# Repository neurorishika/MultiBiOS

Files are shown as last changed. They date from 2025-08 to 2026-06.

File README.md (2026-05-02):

# MultiBiOS: Precision Olfactometer Control System

<div align="center">









**High-precision, hardware-clocked olfactometer control system for behavioral neuroscience**

[📚 Documentation](https://neurorishika.github.io/MultiBiOS/) • [🚀 Quick Start](#quick-start) • [🔧 Installation](#installation) • [📖 Examples](#examples) • [🤝 Contributing](#contributing)

</div>

---

## 🧪 Overview

**MultiBiOS** (Multispecies Bilateral Odor delivery System) is a precision olfactometer control system designed for behavioral neuroscience experiments. It provides sub-millisecond timing control, complete experimental reproducibility, and comprehensive data logging.

### ✨ Key Features

- 🎯 **Sub-millisecond precision** with hardware-clocked timing via NI-DAQ
- 🔄 **Bilateral valve control** for complex comparative experiments  
- 📊 **Complete data provenance** with comprehensive logging and replay
- 🛡️ **Built-in safety guardrails** prevent timing conflicts at compile-time
- 🎲 **Reproducible randomization** via configurable random seeds
- 📈 **Interactive visualization** with real-time and post-hoc analysis
- ⏱️ **Real-time progress monitoring** shows expected protocol state during execution
- 🔌 **Teensy 4.1 firmware** for microsecond-precise valve preloading
- 📝 **YAML protocols** for human-readable experimental descriptions

### 🏗️ System Architecture

```
┌─────────────────┐    ┌─────────────────┐    ┌─────────────────┐
│   YAML Protocol │───▶│ Python Compiler │───▶│   NI-DAQ USB    │
│   Description   │    │   & Runner      │    │    6353         │
└─────────────────┘    └─────────────────┘    └─────────────────┘
                                                        │
                                                        ▼
                              ┌─────────────────────────────────────┐
                              │          Teensy 4.1 MCU             │
                              │    (Valve Pattern Preloading)      │
                              └─────────────────────────────────────┘
                                                │
                                                ▼
                              ┌─────────────────────────────────────┐
                              │       TPIC6B595 Shift Registers    │
                              │         (10MHz SPI Chain)          │
                              └─────────────────────────────────────┘
                                                │
                                                ▼
                              ┌─────────────────────────────────────┐
                              │      Olfactometer Valve Arrays     │
                              │    (8-valve bilateral control)     │
                              └─────────────────────────────────────┘
```

## 🚀 Quick Start

### Prerequisites

- Conda or Miniconda
- NI-DAQmx drivers (for hardware execution)
- Spinnaker SDK 4.3.0.189 installed on Windows before installing `PySpin`
- If you want live Blackfly input in FicTrac on this rig, build a Spinnaker-enabled FicTrac binary and configure the `fictrac` block in `config/hardware.yaml`

### Installation

```bash
# Clone the repository
git clone https://github.com/neurorishika/MultiBiOS.git
cd MultiBiOS

# Create the shared NI-DAQ + Blackfly camera environment
conda env create -f environment.yml
conda activate multibios-blackfly

# Verify the combined stack
python -c "import multibios, nidaqmx, PySpin; print('multibios-blackfly ready')"

# Optional app smoke tests
multibios-explorer --help
multibios-flow-monitor --help
```

This environment is intended to run both the MultiBiOS DAQ stack and the Blackfly camera scripts in one place. The rig camera model is **Teledyne FLIR Blackfly S BFS-U3-13Y3M**.

For live FicTrac on the Blackfly side camera, see `docs/fictrac.md`. MultiBiOS now prepares the Spinnaker runtime DLL path automatically before launching FicTrac, but you still need a FicTrac binary built with the upstream `PGR_USB3` option.

If you are on this workstation and want the same validated build that was used for the Blackfly side camera, run:

```powershell
cd C:\Rishika\MultiBiOS
.\tools\build_fictrac_spinnaker.ps1 -VcpkgRoot C:\Users\markd\vcpkg
```

The resulting binary is expected at `assets/fictrac-spinnaker/fictrac-spinnaker.exe`. The step-by-step build and usage guide lives in `docs/fictrac.md`.

FicTrac is treated as vendored source in this repo because MultiBiOS carries source-level patches in `assets/third_party/FicTrac`. The local build directory `assets/third_party/FicTrac-build` should remain untracked.

### Your First Protocol

1. **Preview a protocol** (no hardware required):
   ```bash
     python -m multibios.run_protocol \
      --yaml protocols/example_protocol.yaml \
       --hardware config/hardware.yaml \
       --dry-run --interactive
   ```

2. **Run on hardware** (requires NI-DAQ setup):
   ```bash
     python -m multibios.run_protocol \
      --yaml protocols/example_protocol.yaml \
       --hardware config/hardware.yaml
   ```

3. **Run with real-time progress monitoring**:
   ```bash
     python -m multibios.run_protocol \
      --yaml protocols/example_protocol.yaml \
       --hardware config/hardware.yaml \
       --verbose --progress
   ```
   
   This displays the expected protocol state during execution:
   ```
   DO Legend: [0:RCK] [1:LOAD_REQ] [2:S0] [3:S1] [4:S2]
   AO Legend: [0:MFC1] [1:MFC2]
   [  5%] 250.0ms | DO:░█░░█ | AO:0:2.50,1:1.20
   [ 10%] 500.0ms | DO:█░█░░ | AO:0:3.00,1:1.50
   ```
   (█=HIGH, ░=LOW, shows all channels at once!)

4. **Analyze results**:
   ```bash
  python -m multibios.viz_protocol data/runs/latest
   ```

## 📖 Examples

### Simple Bilateral Odor Delivery

```yaml
protocol:
  name: "Bilateral Odor Comparison"
  timing:
    sample_rate: 1000  # 1 kHz sampling
    seed: 42          # Reproducible randomization

sequence:
  - phase: "Baseline"
    duration: 30000   # 30 seconds
    times: 1
    actions:
      - device: "olfactometer.left"
        state: "AIR"
        timing: 0
      - device: "olfactometer.right"
        state: "AIR"
        timing: 0

  - phase: "Odor Presentation" 
    duration: 60000   # 1 minute per trial
    times: 5          # 5 trials
    randomize: true   # Randomize odor order
    actions:
      - device: "olfactometer.left"
        state: "ODOR1,ODOR2,ODOR3"  # Random selection
        timing: 10000               # 10s into trial
      - device: "triggers.microscope"
        state: true
        timing: 15000               # Trigger at 15s
```

### Advanced Multi-Device Coordination

```yaml
sequence:
  - phase: "Complex Trial"
    duration: 45000
    times: 10
    actions:
      # MFC setpoints
      - device: "mfc.air_left_setpoint"
        value: 2.1  # Volts
        timing: 0
      
      # Synchronized valve switching  
      - device: "olfactometer.left"
        state: "ODOR1"
        timing: 5000
      - device: "switch_valve.left"
        state: "ODOR" 
        timing: 5100  # 100ms later
        
      # Continuous camera triggers
      - device: "triggers.camera_continuous"
        state: true
        timing: 1000
      - device: "triggers.camera_continuous" 
        state: false
        timing: 40000
```

## 🔧 Hardware Setup

### Required Components

| Component | Description | Quantity |
|---|---|---|
| **NI USB-6353** | Hardware-clocked DAQ | 1 |
| **Teensy 4.1** | Microcontroller for valve control | 1 |
| **TPIC6B595** | High-power shift registers | 4 |
| **Olfactometer valves** | Pneumatic valves (12V) | 8-16 |
| **Mass flow controllers** | Precision flow control | 2-4 |

### Wiring Overview

```
NI-DAQ ────┐
           ├─── LOAD_REQ (Hardware clock)
           ├─── S-bits (Device selection) 
           ├─── Analog I/O (MFC control)
           └─── Triggers (Microscope/Camera)

Teensy ────┐
           ├─── SPI Chain (10MHz)
           ├─── Interrupt handling
           └─── Safety interlocks

TPIC6B595 ─┼─── Valve Array Left
           ├─── Valve Array Right  
           ├─── Switch Valve Left
           └─── Switch Valve Right
```

📋 **[Complete wiring diagrams and setup instructions →](https://neurorishika.github.io/MultiBiOS/hardware/)**

## 📊 Data Output

MultiBiOS provides comprehensive data logging:

### Generated Files
```
data/runs/2025-08-21_14-07-33/
├── protocol_original.yaml      # Original protocol
├── protocol_compiled.yaml      # Compiled with timing  
├── hardware_config.yaml        # Hardware configuration
├── digital_output.npy          # DO timing arrays
├── analog_output.npy           # AO setpoints
├── analog_input.csv            # MFC feedback (if recorded)
├── timing_log.csv              # Execution timestamps
└── visualization.html          # Interactive plot
```

### Interactive Visualization

The system generates rich interactive plots showing:
- 📈 Commanded vs actual valve states
- 🎛️ Analog input/output traces  
- ⏱️ Timing precision analysis
- 🔍 Zoom and pan capabilities

## 🧪 Use Cases

MultiBiOS is designed for:

- **Behavioral choice experiments** with precise odor timing
- **Optogenetics** with synchronized light/odor delivery
- **Calcium imaging** with triggered acquisition
- **Electrophysiology** with sub-millisecond precision
- **Multi-animal** comparative studies
- **Reproducible protocols** across labs and sessions

## 🛡️ Safety & Reliability

### Built-in Safeguards
- ✅ **Compile-time validation** prevents hardware conflicts
- ✅ **Timing guardrails** ensure safe valve switching
- ✅ **State verification** with sticky S-bit monitoring  
- ✅ **Hardware interlocks** prevent damage
- ✅ **Complete logging** for audit trails

### Experimental Reproducibility
- 🎯 **Deterministic randomization** with configurable seeds
- 📝 **Complete parameter logging** 
- 🔄 **Protocol replay** capability
- 📊 **Timing validation** and verification
- 🏷️ **Version tracking** of all components

## 📚 Documentation

Comprehensive documentation is available at **[neurorishika.github.io/MultiBiOS](https://neurorishika.github.io/MultiBiOS/)**

### Quick Links
- 🏗️ [System Architecture](https://neurorishika.github.io/MultiBiOS/hardware/)
- 🔌 [Hardware Setup](https://neurorishika.github.io/MultiBiOS/wiring/) 
- 💾 [Firmware Guide](https://neurorishika.github.io/MultiBiOS/firmware/)
- 📝 [Protocol Reference](https://neurorishika.github.io/MultiBiOS/protocol/)
- 🏃 [Runner Application](https://neurorishika.github.io/MultiBiOS/runner/)
- 📈 [Visualization](https://neurorishika.github.io/MultiBiOS/visualization/)
- ❓ [FAQ](https://neurorishika.github.io/MultiBiOS/faq/)
- 🔧 [Troubleshooting](https://neurorishika.github.io/MultiBiOS/troubleshooting/)

## 🤝 Contributing

We welcome contributions! MultiBiOS is built for the neuroscience community.

### Ways to Contribute
- 🐛 **Report bugs** and request features
- 💡 **Submit improvements** to code or documentation  
- 🧪 **Share protocols** and use cases
- 🔧 **Hardware modifications** and extensions
- 📚 **Documentation** improvements

### Getting Started
```bash
# Fork the repository on GitHub
git clone https://github.com/yourusername/MultiBiOS.git
cd MultiBiOS

# Install development dependencies
poetry install --with dev

# Run tests
poetry run pytest

# Format code
poetry run black multibios/
poetry run ruff check multibios/
```

### Test And Tool Layout

- `tests/` is reserved for automated `pytest` coverage.
- `tools/manual_checks/` is for operator-facing hardware checks, probes, and bench scripts that are meant to be run directly.
- When adding new validation code, put reusable automated assertions under `tests/` and keep live camera, DAQ, MFC, or FicTrac helpers under `tools/manual_checks/`.

For a quick automated smoke pass from the repo root, run:

```bash
pytest tests/
```

📖 **[Full contributing guide →](https://neurorishika.github.io/MultiBiOS/contributing/)**

## 📄 License

This project is licensed under the MIT License - see the [LICENSE](LICENSE) file for details.

## 🙏 Acknowledgments

MultiBiOS was developed for the neuroscience research community. Special thanks to:
- The **Ruta and Kronauer Labs** for requirements and testing
- **National Instruments** for DAQ hardware support  
- The **Arduino/Teensy** community for firmware foundations
- **Open source contributors** who make science better

## 📞 Contact

- **Issues & Support:** [GitHub Issues](https://github.com/neurorishika/MultiBiOS/issues)
- **Email:** neurorishika@gmail.com  
- **Documentation:** [neurorishika.github.io/MultiBiOS](https://neurorishika.github.io/MultiBiOS/)

---

<div align="center">

**🧠 Built for Neuroscience • 🔬 Made with Science • 🚀 Open Source**

[⭐ Star this repo](https://github.com/neurorishika/MultiBiOS/stargazers) • [📖 Read the docs](https://neurorishika.github.io/MultiBiOS/) • [🤝 Contribute](CONTRIBUTING.md)

</div>

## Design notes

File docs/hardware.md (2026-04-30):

# System Architecture

The system separates **state preparation** from **state commit**:

1. **Teensy 4.1** drives SPI MOSI/SCK to all TPIC6B595 chains (no latches).
2. **NI-DAQ** provides:
   - Digital lines for **state selection** (`*_S0/_S1/_S2` or `*_S`) and **LOAD_REQ**.
   - **Register clocks** (`RCK_*`) to latch TPIC outputs—this is the *commit* moment.
   - Triggers to external devices (e.g., microscope, camera).
   - Analog outputs (AO) to set **MFC setpoints**.
   - Analog inputs (AI) to read **MFC flow feedback** (0–5 V).

**Key idea**: the Teensy preloads the next pattern when `*_LOAD_REQ` rises (it samples S-bits), then waits. The DAQ later asserts `RCK_*` to commit the preload. The DAQ can timestamp RCK edges precisely (hardware clock).

## Hardware Blocks

- **Valve drivers**: TPIC6B595 (open-drain high-side sinking arrays).
- **Big olfactometers**: two 16-bit manifolds (use 12 bits now; 4 spares).
- **Small switch valves**: two 2-valve assemblies (8-bit register each; only 2 bits used).
- **MFCs**: Four channels (air L/R, odor L/R). AO setpoint (0–5 V), AI feedback (0–5 V).
- **Timing**: NI USB-6353 sample clock slaves AO & AI to DO.

## Camera Rig

- **Front camera**: Teledyne FLIR Blackfly S BFS-U3-13Y3M, Mono8, USB3
- **Side/FicTrac camera**: Teledyne FLIR Blackfly S BFS-U3-13Y3M, Mono8, USB3
- **Camera SDK**: Spinnaker / PySpin 4.3.0.189 on Windows
- **Shared environment**: `multibios-blackfly`

GPIO findings verified on the live rig cameras:

- `Line1` is the white-wire return path and reports as `OptoCoupled`
- `Line2` is a separate GPIO path and reports as `OpenDrain`
- the blue wire is `Opto GND` for the isolated white-wire output

Documenting the exact camera model and software stack here is intentional: this rig assumes both camera positions use the same Blackfly S hardware so acquisition timing and synchronization checks are repeatable across rebuilds.

## Signal Naming (logical)

Digital outputs (from DAQ to Teensy/TPIC):

- **Left big olfactometer**: `OLFACTOMETER_LEFT_S0/_S1/_S2`, `OLFACTOMETER_LEFT_LOAD_REQ`, `RCK_OLFACTOMETER_LEFT`
- **Right big olfactometer**: `OLFACTOMETER_RIGHT_*` (same fields)
- **Left small switch**: `SWITCHVALVE_LEFT_S`, `SWITCHVALVE_LEFT_LOAD_REQ`, `RCK_SWITCHVALVE_LEFT`
- **Right small switch**: `SWITCHVALVE_RIGHT_*`
- **Triggers**: `TRIG_MICRO`, `TRIG_CAMERA`

Analog:

- **AO (setpoints)**: `mfc.air_left_setpoint`, `mfc.air_right_setpoint`, `mfc.odor_left_setpoint`, `mfc.odor_right_setpoint`
- **AI (feedback)**: `mfc.air_left_flowrate`, `mfc.air_right_flowrate`, `mfc.odor_left_flowrate`, `mfc.odor_right_flowrate`

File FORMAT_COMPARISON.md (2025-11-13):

# Progress Monitor Format Evolution

## Version 1: Original Verbose Format (REJECTED)

```
=== Real-time Progress Monitor Started ===
Protocol duration: 5.00s (5000 samples @ 1000Hz)
Update interval: 100ms

[  2.0%] [t=100.0ms] DO: RCK=LOW, LOAD_REQ=LOW, S0=LOW | AO: MFC1=0.000V, MFC2=0.000V
[  4.0%] [t=200.0ms] DO: RCK=LOW, LOAD_REQ=HIGH, S0=LOW | AO: MFC1=2.500V, MFC2=1.200V
```

**Problems:**
- ❌ Too wordy - hard to scan
- ❌ HIGH/LOW takes too much space
- ❌ Can only show 3-5 channels per line
- ❌ Hard to see patterns

## Version 2: Compact with Names (REJECTED)

```
Progress monitor: 5000 samples @ 1000Hz, updates every 100ms
[  2%] 100.0ms | RCK:░ LOAD_REQ:░ S0:░ S1:░ S2:░ | MFC1:0.00 MFC2:0.00
[  4%] 200.0ms | RCK:░ LOAD_REQ:█ S0:░ S1:█ S2:░ | MFC1:2.50 MFC2:1.20
```

**Better, but:**
- ⚠️ Long channel names still limit visibility
- ⚠️ Can only see 4-5 DO channels
- ⚠️ Shows all AO channels even when zero

## Version 3: Index-Based with Legend (CURRENT ✓)

```
Progress monitor: 5000 samples @ 1000Hz, updates every 100ms
DO Legend: [0:RCK] [1:LOAD_REQ] [2:S0] [3:S1] [4:S2] [5:S3] [6:S4] [7:S5]
AO Legend: [0:MFC1] [1:MFC2] [2:MFC3]
✓ All DAQ tasks started, protocol execution in progress...

[  2%] 100.0ms | DO:░░░░░░░░ | AO:---
[  4%] 200.0ms | DO:░█░█░░░░ | AO:0:2.50,1:1.20
[  6%] 300.0ms | DO:█░█░█░░░ | AO:0:2.50,1:1.20
[  8%] 400.0ms | DO:░░█░░░░░ | AO:0:2.50,1:1.20
[ 10%] 500.0ms | DO:░░░██░░░ | AO:0:1.80,1:0.80
```

**Perfect!**
- ✅ **Shows ALL DO channels** as visual pattern
- ✅ **Only shows active AO channels** (saves space)
- ✅ **Legend printed once** (no repetition)
- ✅ **Ultra-compact** - fits 16+ DO channels easily
- ✅ **Patterns instantly recognizable**

---

## Key Improvements

### 1. Digital Outputs: Pattern Display

**Old approach:**
```
RCK:░ LOAD_REQ:█ S0:░ S1:█ S2:░
```
- Limited to ~5 channels
- Repetitive names

**New approach:**
```
DO:░█░█░░░░
```
- Shows ALL channels
- Clear visual pattern
- Compact and scannable

### 2. Analog Outputs: Show Only Active

**Old approach:**
```
MFC1:0.00 MFC2:0.00 MFC3:0.00
```
- Wastes space on zeros
- Cluttered

**New approach:**
```
AO:---                    (when all zero)
AO:0:2.50,1:1.20         (only non-zero)
```
- Clean when inactive
- Focused on what matters

### 3. Legend System

**Printed once at startup:**
```
DO Legend: [0:RCK] [1:LOAD_REQ] [2:S0] [3:S1] [4:S2]
AO Legend: [0:MFC1] [1:MFC2] [2:MFC3]
```

Then every update just uses indices:
```
[  5%] 250.0ms | DO:░█░░█ | AO:0:2.50
```

**Benefits:**
- No name repetition
- Easy cross-reference
- Scales to many channels

---

## Real-World Examples

### Example 1: 16 Digital Outputs

**Old format would show:**
```
RCK:░ LOAD_REQ:█ S0:█ +13 more
```
😞 Can't see most channels!

**New format shows:**
```
DO:░█████░░░████████
```
😊 See everything at once!

### Example 2: Mostly Inactive MFCs

**Old format:**
```
MFC1:0.00 MFC2:0.00 MFC3:0.00 MFC4:0.00 MFC5:0.00
```
😞 Visual clutter

**New format:**
```
AO:---
```
😊 Clean and clear!

### Example 3: Few Active Channels

**Old format:**
```
MFC1:2.50 MFC2:0.00 MFC3:0.00 MFC4:1.20 MFC5:0.00
```
😞 Hard to spot which are active

**New format:**
```
AO:0:2.50,3:1.20
```
😊 Instantly see channels 0 and 3 are active!

---

## Capacity Comparison

| Format | Max DO Visible | Max AO Visible | Line Length |
|---|---|---|---|
| Version 1 | 3 | 2 | ~100 chars |
| Version 2 | 5 | 3 | ~80 chars |
| **Version 3** | **ALL** | **ALL active** | **~60 chars** |

---

## Pattern Recognition Benefits

The index-based format makes state sequences obvious:

```
[  2%] 100.0ms | DO:░░░░░░░░ | AO:---
[  4%] 200.0ms | DO:█░░░░░░░ | AO:0:2.50
[  6%] 300.0ms | DO:█░░░░░░░ | AO:0:2.50
[  8%] 400.0ms | DO:░█░░░░░░ | AO:0:2.50
[ 10%] 500.0ms | DO:░░█░░░░░ | AO:0:2.50
[ 12%] 600.0ms | DO:░░░█░░░░ | AO:0:2.50
```

You can instantly see:
- First channel scanning across (walking 1-hot pattern)
- MFC stays constant during scan
- Clear temporal pattern

---

## Summary

The index-based format with legend is the **optimal solution** for real-time protocol monitoring:

1. **Scalability**: Shows unlimited DO channels
2. **Efficiency**: Only shows active AO channels
3. **Clarity**: Visual patterns are instantly recognizable
4. **Compactness**: Shortest possible lines
5. **Usability**: Legend maps indices to names

Perfect for monitoring complex protocols with many channels!

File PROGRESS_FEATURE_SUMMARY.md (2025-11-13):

# Real-Time Progress Monitoring - Implementation Summary

## What Was Added

### 1. Core Feature: `ProtocolProgressMonitor` Class
**Location**: `multibios/run_protocol.py`

A background thread-based monitor that displays expected protocol state during DAQ execution.

**Key capabilities:**
- Calculates expected sample position from elapsed time
- Looks up expected DO/AO states from compiled arrays
- Formats and displays state at configurable intervals
- Automatically starts/stops with DAQ execution
- Zero impact on hardware timing

### 2. Command-Line Arguments
**New flags in `run_protocol.py`:**

```bash
--progress                    # Enable real-time progress monitoring
--progress-interval <ms>      # Update interval (default: 100ms)
```

**Usage:**
```bash
python multibios/run_protocol.py \
    --yaml config/example_protocol.yaml \
    --hardware config/hardware.yaml \
    --verbose \
    --progress \
    --progress-interval 100
```

### 3. Example Scripts
**Windows PowerShell**: `examples/run_with_progress.ps1`
**Linux/Mac Bash**: `examples/run_with_progress.sh`

Demonstrate the feature with sensible defaults.

### 4. Documentation
- **Comprehensive guide**: `examples/README_PROGRESS.md`
- **Runner docs update**: `docs/runner.md` (added section on progress monitoring)
- **Main README update**: Added to feature list and quick start

## How It Works

### Architecture

```
┌─────────────────────┐
│  Main Thread        │
│  - DAQ Execution    │
│  - Task Management  │
└──────────┬──────────┘
           │
           │ Starts/Stops
           ▼
┌─────────────────────┐
│  Monitor Thread     │
│  - Time tracking    │
│  - State lookup     │
│  - Display updates  │
└─────────────────────┘
```

### Thread Safety
- Monitor runs in daemon thread (won't block program exit)
- Uses threading.Event for clean shutdown
- No shared mutable state (reads from compiled arrays)
- No DAQ polling (time-based calculation only)

### Performance
- **CPU overhead**: < 0.1%
- **Memory overhead**: Negligible (references existing arrays)
- **Timing impact**: None (independent of DAQ hardware clock)

## Example Output

### During Execution
```
=== Real-time Progress Monitor Started ===
Protocol duration: 5.00s (5000 samples @ 1000Hz)
Update interval: 100ms

✓ All DAQ tasks started, protocol execution in progress...

[  2.0%] [t=100.0ms] DO: RCK=LOW, LOAD_REQ=LOW, S0=LOW | AO: MFC1=0.000V, MFC2=0.000V
[  4.0%] [t=200.0ms] DO: RCK=LOW, LOAD_REQ=HIGH, S0=LOW | AO: MFC1=2.500V, MFC2=1.200V
[  6.0%] [t=300.0ms] DO: RCK=HIGH, LOAD_REQ=LOW, S0=HIGH | AO: MFC1=2.500V, MFC2=1.200V
...
[100.0%] Protocol execution complete

=== Real-time Progress Monitor Stopped ===
✓ Protocol execution completed in 5.02 seconds
```

### Format Breakdown
```
[  5.0%]              ← Progress percentage
[t=250.0ms]           ← Protocol timestamp
DO: RCK=LOW, ...      ← Digital output states (first 3 channels)
AO: MFC1=2.500V, ...  ← Analog output voltages (first 2 channels)
```

## Use Cases

### 1. Long Protocols
- Protocols lasting minutes to hours
- Provides reassurance that execution is proceeding
- Shows estimated completion

### 2. Protocol Development
- Verify state transitions
- Check timing of critical events
- Identify unexpected states

### 3. Debugging
- Pinpoint when issues occur
- Compare expected vs. actual behavior
- Narrow down problematic timing windows

### 4. User Demonstrations
- Show what's happening in real-time
- Build confidence in system operation
- Educational tool for understanding protocols

## Configuration Options

### Update Interval Guidelines

| Interval | Best For | Output Volume |
|---|---|---|
| 50ms | Detailed debugging, timing verification | High |
| 100ms | **Default** - General use, good balance | Medium |
| 200ms | Longer protocols, cleaner output | Low |
| 500ms | Very long protocols (hours), minimal updates | Very Low |

### Verbosity Levels

```bash
# Minimal output (progress only)
--progress

# Standard output (recommended)
--verbose --progress

# Maximum detail (debugging)
--debug --progress
```

## Integration Points

### Modified Code Sections

1. **Imports** (line ~23):
   - Added `threading` module

2. **New Class** (after line ~47):
   - `ProtocolProgressMonitor` class (130 lines)

3. **Argument Parser** (line ~216):
   - Added `--progress` flag
   - Added `--progress-interval` option

4. **DAQ Configuration Info** (line ~546):
   - Added progress monitoring status to log output

5. **DAQ Execution** (line ~636):
   - Initialize monitor if `--progress` enabled
   - Start monitor with DAQ tasks
   - Stop monitor in finally block

### No Changes Required To
- Protocol compiler
- Hardware configuration
- Existing visualization
- Data output format
- DAQ task configuration

## Testing Recommendations

### Basic Functionality
```bash
# Test with short protocol
python multibios/run_protocol.py \
    --yaml config/short_protocol.yaml \
    --hardware config/hardware.yaml \
    --verbose --progress --dry-run
```

### Different Update Intervals
```bash
# Fast updates
--progress --progress-interval 50

# Slow updates  
--progress --progress-interval 500
```

### With/Without Verbose
```bash
# With verbose (recommended)
--verbose --progress

# Without verbose (should still work)
--progress
```

### Hardware Execution
```bash
# Full hardware run with monitoring
python multibios/run_protocol.py \
    --yaml config/example_protocol.yaml \
    --hardware config/hardware.yaml \
    --verbose --progress --interactive
```

## Troubleshooting

### Common Issues

**Issue**: No progress updates appearing
**Solution**: Must use `--verbose` or `--debug` with `--progress`

**Issue**: Updates too frequent/infrequent
**Solution**: Adjust `--progress-interval` value

**Issue**: Monitor doesn't stop cleanly
**Solution**: Uses `finally` block - should always stop. Check logs.

**Issue**: Performance concerns
**Solution**: Monitor has < 0.1% CPU overhead. Can increase interval if needed.

## Future Enhancements

Possible improvements for future versions:

1. **Customizable display format**
   - User-specified which channels to show
   - Custom formatting templates

2. **Progress bar visualization**
   - Terminal-based progress bar (using `tqdm` or similar)
   - Time remaining estimates

3. **Event notifications**
   - Alert on key protocol events (RCK pulses, triggers)
   - Custom event hooks

4. **Web-based monitoring**
   - Real-time web dashboard
   - Remote monitoring capability

5. **Historical comparison**
   - Compare current execution to previous runs
   - Deviation alerts

## Dependencies

No new dependencies required! Uses only standard library:
- `threading` (Python standard library)
- Existing imports (numpy, logging, etc.)

## Backward Compatibility

✅ **Fully backward compatible**
- Feature is opt-in (requires `--progress` flag)
- Existing scripts work unchanged
- No modifications to protocol YAML or hardware config
- Output format unchanged (progress is additional logging)

## Files Modified/Created

### Modified
- `multibios/run_protocol.py` - Added monitor class and integration

### Created
- `examples/run_with_progress.ps1` - PowerShell example
- `examples/run_with_progress.sh` - Bash example
- `examples/README_PROGRESS.md` - Comprehensive user guide
- `docs/runner.md` - Updated with progress monitoring section
- `README.md` - Updated feature list and quick start

### No Changes
- All protocol YAML files
- Hardware configuration
- Compiler logic
- Visualization code
- Test suite

## Summary

This implementation provides real-time visibility into protocol execution without any negative impact on system performance or timing accuracy. It's a purely additive feature that enhances the user experience while maintaining full backward compatibility.

The monitor gives users confidence that their protocols are executing correctly, which is especially valuable during long runs or when developing new experimental procedures.

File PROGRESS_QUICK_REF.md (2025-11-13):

# Real-Time Progress Monitoring - Quick Reference

## Enable Progress Monitoring

```bash
python multibios/run_protocol.py \
    --yaml config/example_protocol.yaml \
    --hardware config/hardware.yaml \
    --verbose \
    --progress
```

## Customize Update Frequency

```bash
# Update every 50ms (more frequent)
--progress --progress-interval 50

# Update every 200ms (less frequent)  
--progress --progress-interval 200
```

## What You'll See

```
DO Legend: [0:RCK] [1:LOAD_REQ] [2:S0] [3:S1] [4:S2] [5:S3]
AO Legend: [0:MFC1] [1:MFC2] [2:MFC3]

[  5%] 250.0ms | DO:░█░█░░ | AO:0:2.50,1:1.20
[ 10%] 500.0ms | DO:█░█░█░ | AO:0:3.00,1:1.50
```

- Legend printed once at start
- `[5%]` = Progress percentage
- `250.0ms` = Current protocol time
- `DO:░█░█░░` = Digital pattern (█=HIGH, ░=LOW)
  - Position matches legend: 0=RCK, 1=LOAD_REQ, etc.
- `AO:0:2.50,1:1.20` = Active analog channels
  - `0:2.50` = Channel 0 (MFC1) at 2.50V
  - Only shows non-zero channels!

## Update Interval Guidelines

| Value | Use Case |
|---|---|
| 50ms  | Detailed debugging |
| 100ms | **Default** (recommended) |
| 200ms | Cleaner output |
| 500ms | Very long protocols |

## Combine with Other Flags

```bash
# Full monitoring with visualization
--verbose --progress --interactive

# Debug mode with progress
--debug --progress --progress-interval 50

# Dry run with progress simulation
--dry-run --verbose --progress
```

## Example Scripts

**Windows:**
```powershell
.\examples\run_with_progress.ps1
```

**Linux/Mac:**
```bash
./examples/run_with_progress.sh
```

## Important Notes

✅ Must use `--verbose` or `--debug` to see progress updates
✅ No impact on DAQ timing accuracy
✅ Works with dry-run mode
✅ Background thread with < 0.1% CPU overhead

❌ Shows expected state, not real-time DAQ feedback
❌ Don't set interval < 20ms (excessive output)

## Full Documentation

See `examples/README_PROGRESS.md` for complete guide.

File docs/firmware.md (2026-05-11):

# Teensy 4.1 Firmware

**Model**: Preload-and-commit with RCK-sense, single-owner SPI bus.

Current primary open-loop firmware source: `firmware/teensy41/src/open_loop_controller/open_loop_controller.ino`

Alternative dual-mode firmware source: `firmware/teensy41/src/dual_mode_controller/dual_mode_controller.ino`

- DAQ asserts `*_LOAD_REQ` → Teensy ISR:
  1. Samples `S` bits for that assembly.
  2. Shifts the corresponding 16-bit (big) or 8-bit (small) pattern via SPI to the daisy chain (no latch).
  3. Sets `READY_*` high and **locks the bus** to that owner.
- DAQ later asserts `RCK_*` → Teensy ISR senses it:
  - Drops `READY_*`, **unlocks the bus**.

> Only **one staged preload** may be pending at a time. The compiler enforces this with **guardrails**.

## State coding

Big manifold (16-bit, using v0..v11, 4 spare):

- `AIR`: v0,v1 = 1
- `ODOR1`: v2,v3 = 1  
…  
- `ODOR5`: v10,v11 = 1  
- `FLUSH`: v0..v11 = 1

Small switch (8-bit, using v0..v1):

- `CLEAN`: both 0  
- `ODOR`:  both 1

The current `open_loop_controller` firmware also emits structured USB serial telemetry for host-side audit logging, including `MODE`, `READY`, `VALVE`, `COMMIT`, and `FAULT` lines.

The `dual_mode_controller` sketch boots in serial-controller mode with a reduced command set (`CTRL`, `OD1`-`OD5`, `CLN`, `ODR`, `RESET`, `TEST START`, `TEST STOP`) and switches into the same DAQ-driven open-loop preload/commit path when it receives `OPENLOOP START`. Use `OPENLOOP STOP` to detach the DAQ interrupts, drop all `READY_*` lines low, and restore the staged serial frame.

Enable host-side transcript capture in `config/hardware.yaml` with:

```yaml
teensy:
  port: "COM4"
  baud: 115200
  capture_serial: true
```

Edit pin mappings and state tables in `firmware/teensy41/src/open_loop_controller/open_loop_controller.ino` if your plumbing differs.

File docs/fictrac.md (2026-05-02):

# FicTrac Integration

This page covers the MultiBiOS-specific path for running FicTrac on this rig, including the current Blackfly camera constraint, how to build a Spinnaker-enabled FicTrac on Windows, and how NI-DAQ-triggered acquisition should be interpreted.

For the internal client architecture, full-state storage model, closed-loop consumer API, and deprecation criteria, see [fictrac_client.md](fictrac_client.md).

## Current State On This Rig

- The packaged Spinnaker build at `C:/Rishika/MultiBiOS/assets/fictrac-spinnaker/fictrac-spinnaker.exe` is the validated binary for this workstation.
- The in-repo MultiBiOS FicTrac client is receiving realtime callback frames from the live Blackfly side camera.
- `multibios.run_protocol` has been validated against live FicTrac on this rig.
- MultiBiOS now sanitizes the Windows child-process environment before launching FicTrac, which avoids the conda/Python DLL path conflict that previously caused native startup crashes.

## Validated Operating Point

The canonical rig configuration now uses the highest display-on rate that has passed repeated artifact-level parity checks on this workstation.

Canonical values in `config/hardware.yaml`:

- `camera_recording.trigger_fps_hz: 142.857143`
- FicTrac `src_fps` is generated from `camera_recording.trigger_fps_hz` at runtime
- effective shared camera interval: `7.0 ms`

Why this is the canonical setting:

- `5.5 ms` failed twice at `999 / 1000` FicTrac frames
- `6.5 ms` failed at `845 / 847` FicTrac frames
- `7.0 ms` passed repeatedly in both FicTrac-only and dual-camera runs with exact parity

Most recent repeatability evidence:

- dual-camera exact parity: `data/runs/2026-05-01_10-27-45`
- dual-camera exact parity: `data/runs/2026-05-01_10-32-14`
- dual-camera exact parity: `data/runs/2026-05-01_10-32-33`
- dual-camera exact parity: `data/runs/2026-05-01_10-32-53`

## Why A Custom Build Is Needed

Upstream FicTrac supports Point Grey / FLIR industrial cameras through two distinct compile-time paths:

- `PGR_USB2` for FlyCapture-era cameras
- `PGR_USB3` for Spinnaker-era cameras

For a Windows Spinnaker build, upstream documents the relevant CMake configuration as:

```powershell
cmake -A x64 `
  -D CMAKE_TOOLCHAIN_FILE=<vcpkg>\scripts\buildsystems\vcpkg.cmake `
  -D PGR_USB3=ON `
  -D PGR_DIR="C:\Program Files\Teledyne\Spinnaker" `
  ..
```

The shared MultiBiOS environment now prepares the SDK runtime search path before launching FicTrac, and the launcher strips conflicting Python/conda DLL search paths on Windows before spawning the native process. That combination is what is currently validated through `multibios.run_protocol` and `tests/fictrac_live_probe.py`.

## Source Of Truth For FicTrac In This Repo

MultiBiOS now treats FicTrac as vendored source, not a disposable upstream clone.

That is intentional because this rig needs source-level changes inside FicTrac itself to work reliably with the MultiBiOS trigger model.

Practical consequences:

- `assets/third_party/FicTrac` is the source of truth and may contain local MultiBiOS-specific patches
- `assets/third_party/FicTrac-build` is only a local build directory and should stay untracked
- `assets/fictrac-spinnaker` is a packaged runtime output, not the editable source tree
- `assets/third_party/FicTrac/MULTIBIOS_PATCHSET.md` is the source-adjacent manifest for the maintained native fork

The build helper no longer silently fetches upstream and checks out `master`. That behavior was unsafe once local patches became part of the rig setup.

## Publication Status

The FicTrac changes are now documented in two layers inside this repo:

- this page documents the full integration behavior and validation history
- `assets/third_party/FicTrac/MULTIBIOS_PATCHSET.md` documents the native fork boundary next to the vendored source tree

Preferred publication model for the lab organization:

1. Create a standalone lab-owned fork repository for the native FicTrac patch set.
2. Publish the full patched source tree there, preserving upstream license and attribution.
3. Keep MultiBiOS as the downstream consumer that pins a known commit or release from that fork.

Why that split is cleaner:

- the native patch set and the Python integration have different maintenance boundaries
- native camera fixes should be versioned independently from experiment-runner changes
- it avoids treating a packaged executable in this repo as the only durable record of the fork

What this repo now contains to make that publication straightforward:

- a source-adjacent native patch manifest
- rebuild instructions for the validated Windows Spinnaker toolchain
- a validated operating point in the canonical hardware config
- a standalone publication scaffold at `Fictrac-TrigWin/` for the planned lab-owned repo

What is still missing for an actual external publication:

- creation of the remote lab-owned repository
- import of the patched FicTrac source history or an initial fork snapshot
- release tags that map packaged binaries to published source commits

## First-Frame Trigger Failure On This Rig

The April 2026 blocker on this workstation was not the MultiBiOS-side `fictrac_timeout_s` setting. It was the upstream Spinnaker first-frame wait inside FicTrac itself.

The confirmed failure signature was:

- protocol path: `protocols/odor_lateralization.yaml`
- runtime config path: `C:\Rishika\data\runs\2026-04-29_23-34-01\fictrac_runtime_config.txt`
- unpatched binary behavior: exits in about 1 s before any UDP frame arrives
- direct console error:

```text
Error grabbing frame! Error was: Spinnaker: Failed waiting for EventData on NEW_BUFFER_DATA event. (GenTL error code: -1011) [-1011]
```

The root cause is in upstream FicTrac's Spinnaker camera path:

- `assets/third_party/FicTrac/src/PGRSource.cpp`
- `PGRSource::grab()`
- `GetNextImage(timeout)` used a hard-coded minimum wait of `1000` ms when `src_fps = -1`

That is too short for a hardware-triggered startup where the first camera pulse may be delayed.

## Exact Custom Patch History

The vendored FicTrac tree now contains these local source edits that matter on this rig.

### 1. Spinnaker 4.x conversion compatibility

File:

- `assets/third_party/FicTrac/src/PGRSource.cpp`

Edit made:

- switched the Spinnaker conversion path to `ImageProcessor().Convert(..., PixelFormat_BGR8)`
- set the processor color handling explicitly with `SPINNAKER_COLOR_PROCESSING_ALGORITHM_NEAREST_NEIGHBOR`

Why it exists:

- the older conversion call pattern used by upstream did not match the Spinnaker 4.x SDK on this workstation

### 2. First-frame wait is now configurable instead of fixed at 1 s

Files:

- `assets/third_party/FicTrac/include/PGRSource.h`
- `assets/third_party/FicTrac/src/PGRSource.cpp`
- `assets/third_party/FicTrac/src/Trackball.cpp`

Edits made:

- `PGRSource` now accepts a `first_frame_timeout_ms` constructor argument
- `Trackball.cpp` reads `src_first_frame_timeout_ms` from the FicTrac config and passes it into `PGRSource`
- the Spinnaker path still uses the normal per-frame timeout after tracking starts
- for the very first frame only:
  - positive `src_first_frame_timeout_ms` values wait that many milliseconds
  - `0` or any negative value means wait indefinitely for the first trigger

Why it exists:

- the upstream Spinnaker live-camera path aborted too early for hardware-triggered startup on this rig
- we need to be able to arm FicTrac before the DAQ trigger train or animal recording starts

### 3. Exception cleanup no longer assumes an image object exists

File:

- `assets/third_party/FicTrac/src/PGRSource.cpp`

Edit made:

- exception paths now guard `pgr_image->Release()` with a null check

Why it exists:

- a failed first grab should report the real capture error, not cascade into a null-image cleanup bug

### 4. The classic FicTrac configuration UI now defaults this setting to `0`

Files:

- `assets/third_party/FicTrac/src/ConfigGUI.cpp`

Edits made:

- `configGui` now seeds `src_first_frame_timeout_ms` to `0` when the key is missing
- when `configGui` opens a live PGR/Spinnaker camera, it now passes that configured value into `PGRSource`

Why it exists:

- there is no separate MultiBiOS reconfiguration path for FicTrac calibration today
- the real reconfiguration workflow is still the upstream `configGui.exe` UI
- when that UI is re-run on this rig, it should preserve the rig-safe default of waiting indefinitely for the first trigger unless the user chooses a different value

### 5. Windows shutdown now uses a real graceful-stop path

Files:

- `assets/third_party/FicTrac/exec/fictrac.cpp`
- `assets/third_party/FicTrac/include/PGRSource.h`
- `assets/third_party/FicTrac/src/PGRSource.cpp`
- `assets/third_party/FicTrac/src/FrameGrabber.cpp`
- `multibios/fictrac_client.py`
- `multibios/run_protocol.py`
- `multibios/blackfly/triggered_camera_record.py`

Edits made:

- the Windows FicTrac entrypoint now handles `SIGBREAK` in addition to `SIGINT`
- `PGRSource::~PGRSource()` now calls `DeInit()` before the camera list and Spinnaker system are released
- the Spinnaker `NEW_BUFFER_DATA` / `GenTL error code: -1011` condition at end-of-trigger is now treated as a clean stream end rather than a fatal grab failure
- `FrameGrabber` now logs a normal input-stream end when the source closed itself cleanly
- the MultiBiOS driver still uses `CTRL_BREAK_EVENT` first on Windows, but that signal now lands in FicTrac's own shutdown path instead of hard-killing the process
- `run_protocol` now stops the second triggered Blackfly recorder before the generic DAQ teardown path finishes unwinding

Why it exists:

- a hard Windows console break or process termination can bypass the cleanup path that releases the Spinnaker camera cleanly
- this rig uses externally triggered Blackfly cameras, so a finite trigger train can end before the parent process explicitly asks FicTrac to stop
- on this rig, treating end-of-trigger as a fatal camera error left the FicTrac camera in a non-editable ROI state after otherwise successful runs

## The Right Way To Kill FicTrac On This Rig

Use a graceful stop, not a hard kill.

Validated shutdown contract:

- on Windows, MultiBiOS should request shutdown with `CTRL_BREAK_EVENT`
- the FicTrac executable must handle that as `SIGBREAK` and unwind normally through `Trackball`, `FrameGrabber`, and `PGRSource`
- the Spinnaker camera path must reach `EndAcquisition()` and `DeInit()` before process exit
- if the finite NI-DAQ trigger train ends first, the Spinnaker `NEW_BUFFER_DATA` / `-1011` condition should be treated as end-of-stream, not as a fatal crash
- the second triggered Blackfly recorder should be asked to stop before late generic task cleanup, so its capture loop sees shutdown intent instead of an unexplained trigger disappearance

Do not rely on these as the primary shutdown path:

- `TerminateProcess`
- `kill()`
- `Popen.terminate()` on Windows as the first stop attempt
- assuming that a finite hardware trigger train ending by itself is equivalent to a clean FicTrac shutdown

Those paths are still acceptable only as last-resort fallbacks when the process is already unresponsive.

Healthy shutdown signatures validated on this workstation:

- probe path: `fictrac_driver_diagnostics.json` ends with `stop_method: "ctrl_break"` and `final_returncode: 0`
- maintained protocol path: FicTrac logs `PGR trigger stream ended; closing camera cleanly.` followed by `Input stream ended.`
- post-run camera inspection reports writable ROI nodes again (`width_writable=true`, `height_writable=true`)

## Raw Recording Format

FicTrac raw camera recording in this repo no longer depends on a single native `VideoWriter` AVI flush during shutdown.

The native path now writes a chunked raw frame stream:

- `fictrac-raw-<timestamp>.json`: manifest with geometry, fps, and chunk paths
- `fictrac-raw-<timestamp>-index.csv`: per-frame index aligned to FicTrac `log_frame`
- `fictrac-raw-<timestamp>-chunkNNNNNN.bin`: BGR8 frame chunks

After the run, MultiBiOS reconstructs those chunks into a lossless review video and includes the result in `fictrac_camera_recording.json`.

### What reconstructs the bins into a video

The reconstruction path lives in `multibios/fictrac_raw_recording.py` and is called automatically from `multibios/run_protocol.py` at the end of a protocol run.

Operationally, the postprocess step does this:

1. discover the newest `fictrac-raw-*.json` manifest in the run directory
2. load `frame_width`, `frame_height`, `channels`, `fps`, and `chunk_paths` from that manifest
3. read `fictrac-raw-*-index.csv` and count valid indexed frames
4. stream each `.bin` chunk back through NumPy memmaps in chunk order
5. write a lossless review video named `fictrac-raw-<timestamp>-lossless.avi` or `.mkv`
6. store the result in `fictrac_camera_recording.json` under `lossless_video`

The writer currently tries the same codec/container candidates used elsewhere in MultiBiOS:

- `FFV1` in `.avi`
- `HFYU` in `.avi`
- `FFV1` in `.mkv`

### What must exist to reconstruct a FicTrac run later

For a completed run, these files are the minimum useful set for re-running reconstruction:

- `fictrac-raw-<timestamp>.json`
- `fictrac-raw-<timestamp>-index.csv`
- every referenced `fictrac-raw-<timestamp>-chunkNNNNNN.bin`

The manifest is the source of truth for geometry and chunk order. The CSV index is the source of truth for saved-frame accounting. The `.bin` chunks contain the actual frame payload.

If the bins are missing, MultiBiOS can still report previously computed metadata from `fictrac_camera_recording.json`, but it cannot regenerate the lossless review video.

### Manual reconstruction for an existing run

If a run already contains FicTrac chunks but does not yet contain the final lossless video, you can reconstruct it by re-running the same Python postprocess function that `run_protocol.py` uses.

From the MultiBiOS repo root:

```powershell
C:/ProgramData/miniconda3/Scripts/conda.exe run -p C:\Users\markd\.conda\envs\multibios-blackfly --no-capture-output python -c "from pathlib import Path; import json; from multibios.fictrac_raw_recording import postprocess_fictrac_raw_recording; run_dir = Path(r'C:\Rishika\MultiBiOS\data\runs\2026-05-01_20-28-46'); summary = postprocess_fictrac_raw_recording(run_dir=run_dir, runtime_info=json.loads((run_dir / 'fictrac_runtime.json').read_text(encoding='utf-8')), frame_count=None, expected_frame_count=None, legacy_raw_videos=[], legacy_saved_raw_frames=None); print(summary['lossless_video'])"
```

Practical notes:

- run this from the repo root so any repo-relative paths in the manifest resolve the same way they did during protocol teardown
- if `fictrac_runtime.json` is missing, you can still reconstruct as long as the manifest contains `fps`; if it does not, you must supply an equivalent `camera_fps` value in `runtime_info`
- the output video basename is derived from the manifest name, so re-running reconstruction rewrites the same `*-lossless.avi` or `*.mkv` target

### How frame counts are interpreted

The reconstruction summary in `fictrac_camera_recording.json` intentionally separates several counts:

- `callback_frames`: frames seen by the Python callback path
- `saved_raw_frames`: frames confirmed from the raw recording postprocess
- `lossless_video.frames_written`: frames emitted into the review video
- `expected_frames`: usually trigger-count derived when protocol validation is enabled

For chunked runs, `saved_raw_frames` comes from the CSV index, not from blindly trusting the manifest's `saved_frames` field and not from trusting an AVI container header.

That means the correct parity check is against `fictrac_camera_recording.json`, not against the raw chunk count alone.

### Interaction with automatic raw chunk cleanup

`hardware.yaml` can now control whether raw chunk files are retained after validation with:

```yaml
camera_recording:
  raw_chunk_retention_policy: keep # or delete_after_parity
```

Behavior:

- `keep`: retain all `.bin` chunks after postprocess
- `delete_after_parity`: delete FicTrac and second-camera `.bin` chunks only after parity checks pass and the final lossless videos validate successfully

When cleanup runs, `fictrac_camera_recording.json` is annotated with `raw_chunk_cleanup` and `raw_chunks_retained`. The manifest is also annotated.

Important consequence: once cleanup has deleted the `.bin` chunks, the run still keeps the final lossless video and summary metadata, but you can no longer reconstruct the review video from raw chunks because the raw payload is gone.

Implementation detail that matters on this rig:

- raw frames are now written on FicTrac's main tracking loop, not on the optional draw/debug queue, so debug backpressure cannot silently drop saved raw frames
- MultiBiOS treats the CSV index as the authoritative saved-frame record and ignores an incomplete trailing CSV row if shutdown interrupts the last buffered line write

Why this exists:

- shutdown is no longer blocked on native AVI finalization
- long triggered experiments can stream frames incrementally to disk
- frame-count validation now comes from the CSV index instead of inferring success from an AVI container flush

Backward compatibility:

- older runs that only contain `fictrac-vidLogFrames-*.txt` are still summarized by the Python postprocess path as a fallback

### Effective behavior after these edits

- first frame wait default in tracking path: `30000` ms
- first frame wait override: `src_first_frame_timeout_ms`
- infinite first frame wait: set `src_first_frame_timeout_ms: 0`
- subsequent frame waits: unchanged upstream logic (`max(1000, 1000 / fps)`)
- default when re-running `configGui.exe` on a config that does not already have the key: `0`

For the exact MultiBiOS validation path used in this repo, the canonical config keeps `src_first_frame_timeout_ms: 0` in `config/config_camera.txt`, and `config/hardware.yaml` can independently bound or unbound the Python-side wait with `fictrac.startup_timeout_s`.

## Exact Rebuild Procedure Used On This Workstation

This is the exact rebuild flow that produced the working packaged binary on this machine.

Validated local paths:

- MultiBiOS repo root: `C:\Rishika\MultiBiOS`
- FicTrac source checkout: `C:\Rishika\MultiBiOS\assets\third_party\FicTrac`
- FicTrac build directory: `C:\Rishika\MultiBiOS\assets\third_party\FicTrac\build`
- Packaged output directory: `C:\Rishika\MultiBiOS\assets\fictrac-spinnaker`
- vcpkg root: `C:\Users\markd\vcpkg`
- Spinnaker SDK root: `C:\Program Files\Teledyne\Spinnaker`
- generator: `Visual Studio 17 2022`

Required tools already installed on this PC:

- `cmake`
- Visual Studio Build Tools 2022
- Spinnaker SDK 4.3.x matching the runtime camera stack
- `vcpkg` with OpenCV, NLopt, and FFmpeg dependencies available through the toolchain

Configure:

```powershell
cmake -S "C:\Rishika\MultiBiOS\assets\third_party\FicTrac" `
  -B "C:\Rishika\MultiBiOS\assets\third_party\FicTrac\build" `
  -G "Visual Studio 17 2022" `
  -A x64 `
  -D CMAKE_TOOLCHAIN_FILE="C:\Users\markd\vcpkg\scripts\buildsystems\vcpkg.cmake" `
  -D PGR_USB3=ON `
  -D PGR_DIR="C:\Program Files\Teledyne\Spinnaker" `
  --fresh
```

Build:

```powershell
cmake --build "C:\Rishika\MultiBiOS\assets\third_party\FicTrac\build" `
  --config Release `
  --parallel
```

Promote the rebuilt executable into the packaged runtime directory used by MultiBiOS:

```powershell
Copy-Item "C:\Rishika\MultiBiOS\assets\third_party\FicTrac\bin\Release\fictrac.exe" `
  "C:\Rishika\MultiBiOS\assets\fictrac-spinnaker\fictrac-spinnaker.exe" -Force

Copy-Item "C:\Rishika\MultiBiOS\assets\third_party\FicTrac\bin\Release\fictrac.exe" `
  "C:\Rishika\MultiBiOS\assets\fictrac-spinnaker\fictrac.exe" -Force

Copy-Item "C:\Rishika\MultiBiOS\assets\third_party\FicTrac\bin\Release\configGui.exe" `
  "C:\Rishika\MultiBiOS\assets\fictrac-spinnaker\configGui.exe" -Force
```

The rebuild completed successfully with the current source patch set on this workstation.

The existing helper script `tools/build_fictrac_spinnaker.ps1` is still usable, but it now assumes the vendored source tree already exists and should not be reset automatically. The commands above are the exact ones that were used for this recovery.

## Helper Script Behavior

The helper script now defaults to the safe vendored-source workflow:

- it expects the patched FicTrac tree at `assets/third_party/FicTrac`
- it uses `assets/third_party/FicTrac-build` only as a local build directory
- it does not fetch or check out upstream refs unless you ask it to explicitly

Default usage:

```powershell
cd C:\Rishika\MultiBiOS

.\tools\build_fictrac_spinnaker.ps1 `
  -VcpkgRoot C:\Users\markd\vcpkg `
  -SpinnakerRoot "C:\Program Files\Teledyne\Spinnaker"
```

If you need to seed a fresh checkout into the vendored source path, do that explicitly:

```powershell
cd C:\Rishika\MultiBiOS

.\tools\build_fictrac_spinnaker.ps1 `
  -VcpkgRoot C:\Users\markd\vcpkg `
  -BootstrapClone
```

If you intentionally want to move the vendored tree to another upstream ref, do it explicitly as well:

```powershell
cd C:\Rishika\MultiBiOS

.\tools\build_fictrac_spinnaker.ps1 `
  -VcpkgRoot C:\Users\markd\vcpkg `
  -FetchUpstream `
  -CheckoutRef <tag-or-commit>
```

That separation matters because a local patched vendor tree and a local build tree are two different things. Only the source tree should carry rig-specific fixes.

## What The Build Produces

After a successful build, the packaged directory should contain at least:

- `fictrac-spinnaker.exe`
- `fictrac.exe`
- `configGui.exe`
- OpenCV / FFmpeg / NLopt runtime DLLs copied beside the executable

On this rig, the primary binary to use is:

```text
C:/Rishika/MultiBiOS/assets/fictrac-spinnaker/fictrac-spinnaker.exe
```

MultiBiOS prepares the runtime `PATH` automatically before launching FicTrac, so you do not need to manually prepend the Spinnaker DLL folder when using the MultiBiOS runners.

If the build succeeds, point `hardware.yaml -> fictrac.bin` at:

```yaml
fictrac:
  bin: "C:/Rishika/MultiBiOS/assets/fictrac-spinnaker/fictrac-spinnaker.exe"
```

## How To Use The Rebuilt Binary

Use the rebuilt binary in three layers, in order: bounded live probe, bounded runner validation, then full experiment.

## Re-running FicTrac Configuration

There is not currently a separate MultiBiOS-side codepath that reconfigures FicTrac calibration for you.

The correct reconfiguration path is still the classic upstream FicTrac UI:

```powershell
cd C:\Rishika\MultiBiOS\assets\fictrac-spinnaker

./configGui.exe C:\Rishika\MultiBiOS\config\config_camera.txt
```

For this rig, that is now safe to use as the standard reconfiguration workflow because the patched `configGui.exe` will default `src_first_frame_timeout_ms` to `0` if the key is missing and will honor the configured value when it opens the live Spinnaker camera.

If you prefer a bounded wait in the UI, set `src_first_frame_timeout_ms` to a positive millisecond value before launching `configGui.exe`.

Because the camera is normally left in external-trigger mode on this rig, the plain upstream workflow is still awkward: `configGui.exe` needs frames to already be arriving before its first `grab()` succeeds.

The easiest packaged workflow is now:

```powershell
cd C:\Rishika\MultiBiOS

./tools/run_fictrac_config_gui.ps1 `
  -Fps 30
```

That helper:

- reapplies the rig's Blackfly defaults from `config/hardware.yaml`
- prepends the required FicTrac/Spinnaker runtime DLL paths
- starts `tests/continuous_camera_trigger.py`
- launches the packaged `configGui.exe` in its own interactive console window
- stops the trigger train when the UI exits

For this rig, the relevant defaults now live in [hardware.yaml](../config/hardware.yaml) under `blackfly_defaults`:

```yaml
blackfly_defaults:
  exposure_us: 4500
  roi_width: 400
  roi_height: 400
```

That means re-running the FicTrac UI helper will first put both cameras into the same `400x400` centered ROI and `4500 us` exposure mode before calibration starts, so the resulting FicTrac ROI is calibrated against the actual cropped sensor image rather than the old full-frame geometry.

If you already have a trigger source running, pass `-NoTriggerTrain` and use the classic UI launch directly.

## Quick Start For This Rig

If you only want the shortest known-good path on this workstation, use these exact steps.

### 1. Optional: Start a trigger train for probe/config workflows

```powershell
cd C:\Rishika\MultiBiOS
conda run -n multibios-blackfly python tests\continuous_camera_trigger.py --fps 30
```

Use this when your current FicTrac camera config expects external triggers during probing or `configGui` calibration.

### 2. Probe the live camera path directly

```powershell
cd C:\Rishika\MultiBiOS
conda run -n multibios-blackfly python tests\fictrac_live_probe.py `
  --frames 5 `
  --config C:\Rishika\MultiBiOS\config\config_camera.txt `
  --fictrac-bin C:\Rishika\MultiBiOS\assets\fictrac-spinnaker\fictrac-spinnaker.exe
```

### Expected outcome

- the trigger process keeps running in terminal 1
- terminal 2 reports callback setup and received frames
- the summary ends with non-zero `frames_received`

### 3. Validate the bounded runner paths

Short hardware-timed validation:

```powershell
cd C:\Rishika\MultiBiOS
conda run -n multibios-blackfly python -m multibios.run_protocol `
  --yaml protocols/short_protocol.yaml `
  --hardware config/hardware.yaml `
  --verbose --progress
```

Expected result:

- a fresh `data/runs/<timestamp>/` directory is created
- `fictrac_driver_diagnostics.json` contains a non-null `first_packet_wall_time`
- the run exits without leaving a `fictrac-spinnaker.exe` process behind

### 4. Then run the full experiment path

After the probe succeeds, use the hardware-timed primary runner with FicTrac enabled in `hardware.yaml`:

```powershell
cd C:\Rishika\MultiBiOS
conda run -n multibios-blackfly python -m multibios.run_protocol `
  --yaml protocols/example_protocol.yaml `
  --hardware config/hardware.yaml `
  --verbose --progress
```

## Using FicTrac From MultiBiOS Runners

### `multibios.run_protocol`

Set the rig-level FicTrac paths in [config/hardware.yaml](../config/hardware.yaml):

```yaml
fictrac:
  bin: "C:/Rishika/MultiBiOS/assets/fictrac-spinnaker/fictrac-spinnaker.exe"
  config: "config_camera.txt"
  first_frame_timeout_ms: 0
  startup_timeout_s: 90.0
```

The canonical FicTrac config now lives at `config/config_camera.txt`, next to `hardware.yaml`. Reconfiguration helpers, probes, and experiment runners should all use that single file.

In this mode, MultiBiOS:

- prepares the Spinnaker runtime path
- launches FicTrac before the DO waveform starts
- waits for the first FicTrac UDP frame using `hardware.yaml -> fictrac.startup_timeout_s`
- starts the hardware-timed protocol only after FicTrac is healthy
- records DAQ outputs and FicTrac artifacts into the same run directory

### Legacy serial runner

`multibios.experiment` is deprecated. Its FicTrac bring-up notes now live in [legacy/serial_experiment_pipeline.md](legacy/serial_experiment_pipeline.md).

## Recommended Bring-Up Sequence

For this specific rig, the safest order is:

1. Confirm SpinView can see the Blackfly camera.
2. Confirm the camera is configured for external trigger mode.
3. Rebuild FicTrac with `PGR_USB3` support if the packaged binary is missing or stale.
4. If your current camera config expects triggers during probing, run `tests/continuous_camera_trigger.py` to provide a known trigger train.
5. Run `tests/fictrac_live_probe.py` against `fictrac-spinnaker.exe`.
6. Run `multibios.run_protocol` with `protocols/short_protocol.yaml`.
7. If you are maintaining the deprecated serial runner, use the bounded legacy procedure in [legacy/serial_experiment_pipeline.md](legacy/serial_experiment_pipeline.md).
8. Only then switch to a full experimental protocol.

That sequence separates build problems, camera-open problems, and trigger-path problems into distinct steps.

## Rig-Specific Notes

- The camera path that matters here is the live Blackfly side camera, not a prerecorded video source.
- SpinView recognition plus FlyCapture failure is consistent with a Spinnaker-only workflow on this hardware.
- DAQ trigger edges remain the authoritative timing reference even when FicTrac is consuming hardware-triggered frames.
- The current camera return-line path should not yet be treated as validated per-frame exposure proof.

## NI-DAQ Triggered FicTrac: What It Means

The important distinction is that **FicTrac does not become the timing master** just because it reads a hardware-triggered camera.

For this rig, the clean timing model is:

1. NI-DAQ generates `TRIG_CAMERA` pulses.
2. The Blackfly camera is armed for external `FrameStart` triggering.
3. FicTrac receives frames only when those DAQ pulses occur.
4. MultiBiOS logs the DAQ waveform and uses it as the authoritative experiment clock.

This gives you hardware-triggered imaging and deterministic frame issuance, but the truth source for alignment is still the DAQ waveform, not FicTrac's host-side arrival time.

## What Must Already Be True

Before a triggered FicTrac run will work reliably:

- The Blackfly side camera must be configured for external trigger mode.
- The trigger rate must be below the camera's real triggered limit for the chosen exposure.
- Exposure time must fit within the trigger period with readout margin.
- The DAQ task must be armed before FicTrac blocks on its first externally triggered frame.
- The FicTrac binary must tolerate a delayed first trigger pulse.

The supported runner now follows that startup requirement before protocol execution and waits up to `hardware.yaml -> fictrac.startup_timeout_s` for the first UDP frame.

For focused trigger acceptance checks, run `tests/verify_camera_trigger_path.py --arm-cameras ...`.
It now reports three things that matter for 200 Hz debugging:

- aggregate trigger acceptance on the DAQ return lines and in direct PySpin acquisition
- missing-edge classification (`exact`, `missing_internal`, or `missing_boundary` when first-vs-last cannot be proven from timing alone)
- timing budget readback from the armed camera state, including actual exposure, actual trigger delay, overlap mode, and remaining slack versus the trigger period

## What MultiBiOS Can Trust Today

What is already validated:

- NI-DAQ can issue camera trigger pulses.
- The Blackfly cameras can acquire on external trigger in the existing Blackfly tests.
- The internal MultiBiOS FicTrac client receives realtime UDP callbacks when FicTrac is healthy.
- The rebuilt `fictrac-spinnaker.exe` can run the live Blackfly path on this rig.
- The Windows child-process launch path used by both MultiBiOS runners is validated on this workstation.

What is already validated in saved run artifacts:

- bounded `multibios.run_protocol` execution with FicTrac frames written into the DAQ run directory
- deprecated serial-runner validation notes have been moved to [legacy/serial_experiment_pipeline.md](legacy/serial_experiment_pipeline.md)

What is not yet fully validated:

- Camera output return timing on the existing `O1` line wiring.

The current wiring notes indicate that the Blackfly white output line requires the blue opto ground reference, or another external bias path, before it will become a reliable DAQ-visible return.

## Recommended Synchronization Strategy

Use this hierarchy for timestamp trust:

1. **DAQ waveform edges** for experiment event timing.
2. **Camera return line edges**, once validated, for proof that each hardware trigger produced a real exposure.
3. **FicTrac frame order** for behavioral reconstruction.
4. **FicTrac host arrival timestamps** only as a convenience field, not as the primary synchronization source.

That structure is what lets you say both of these things at once without contradiction:

- the camera is hardware-triggered by NI-DAQ
- FicTrac still runs as a downstream consumer rather than the clock authority

## Immediate Next Checks After Rebuild

After rebuilding FicTrac with `PGR_USB3` support:

1. Reproduce the old failure directly with the packaged binary and a delayed/no-trigger runtime config if you need to confirm the root cause again.
2. Run the rebuilt binary against that same runtime config and confirm it stays alive past the old 1 s failure point.
3. Run `tests/fictrac_live_probe.py` against the rebuilt binary and the live camera config.
4. Run a short MultiBiOS experiment with camera triggers enabled.
5. Compare frame count against DAQ trigger count.
6. Validate a camera return line before treating per-frame exposure confirmation as solved.

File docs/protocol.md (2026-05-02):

# YAML Protocol Specification

This document describes the YAML protocol format for defining olfactometer experiments with precise timing control.

## Protocol Structure Overview

A protocol consists of three main sections:

- **Protocol metadata**: Name, version, and description
- **Timing configuration**: Sample rates, pulse widths, and timing constraints
- **Sequence definition**: Phases with device actions and precise timing

## Top-Level Configuration

```yaml
protocol:
  name: "Descriptive Protocol Name"
  version: "1.0"
  description: "Detailed description of the experimental paradigm"
  timing:
    base_unit: "ms"                    # Time unit for all timing values
    sample_rate: 1000                  # Hz - 1000=1ms precision, 10000=0.1ms precision
    preload_lead_ms: 2                 # ms - S-bits switch before LOAD_REQ pulse
    load_req_ms: 1                     # ms - duration of LOAD_REQ pulses
    rck_pulse_ms: 1                    # ms - duration of register clock (RCK) pulses
    trig_pulse_ms: 5                   # ms - duration of microscope trigger pulses
    setup_hold_samples: 100            # samples - S-bit stability margin around load events
    seed: 42                           # RNG seed for reproducible randomization (optional)

sequence:
  - phase: "Phase Name"
    duration: 30000                    # ms - total phase duration
    times: 5                           # number of repetitions (preferred over 'repeat')
    repeat: 0                          # legacy: 0=no repeat, 1=repeat once
    randomize: true                    # randomize order within state lists
    actions:
      - device: "device.name"
        state: "STATE_NAME"            # for digital devices
        value: 2.5                     # for analog devices (volts)
        timing: 1000                   # ms - offset within phase
```

## Timing Configuration Details

### Sample Rate & Precision

- **sample_rate**: Determines temporal resolution
  - `1000` Hz = 1 ms precision (standard)
  - `10000` Hz = 0.1 ms precision (high precision)
- **base_unit**: Always "ms" for millisecond timing

### Hardware Pulse Timing

- **preload_lead_ms**: Time before LOAD_REQ when S-bits switch to new state
- **load_req_ms**: Duration of load request pulses sent to Teensy
- **rck_pulse_ms**: Duration of register clock pulses for valve commits
- **setup_hold_samples**: Extra samples for S-bit stability around load events

### Camera & Trigger Timing  

- Camera trigger cadence and pulse width are hardware-owned and come from `camera_recording.trigger_fps_hz` and `camera_recording.trigger_pulse_ms` in `config/hardware.yaml`
- **trig_pulse_ms**: Width of microscope trigger pulses

## Device Types & States

## Device Configuration Reference

### Olfactometers (8-Valve Systems)

Control large olfactometer valve arrays with 8 possible states.

**Device Keys:**

- `olfactometer.left` - Left olfactometer system
- `olfactometer.right` - Right olfactometer system

**Available States:**

- `OFF` - All valves closed (state 0)
- `AIR` - Clean air delivery (state 1)
- `ODOR1` through `ODOR5` - Specific odor channels (states 2-6)
- `FLUSH` - System flush/clean (state 7)

**Multi-State Selection:**

```yaml
# Single state
state: "ODOR1"

# Sequential selection (uses repeat index)  
state: "ODOR1,ODOR2,ODOR3"

# Copy from other side
state: "COPY"  # mirrors the resolved left olfactometer state
```

### Switch Valves (2-State Systems)

Control binary switch valves for clean/odor selection.

**Device Keys:**

- `switch_valve.left` - Left switch valve
- `switch_valve.right` - Right switch valve  

**Available States:**

- `CLEAN` - Clean air path (state 0)
- `ODOR` - Odor delivery path (state 1)

### Mass Flow Controllers (Analog Outputs)

Set voltage levels (0-5V) for MFC setpoints.

**Device Keys:**

- `mfc.air_left_setpoint` - Left air MFC setpoint
- `mfc.air_right_setpoint` - Right air MFC setpoint
- `mfc.odor_left_setpoint` - Left odor MFC setpoint  
- `mfc.odor_right_setpoint` - Right odor MFC setpoint

**Usage:**

```yaml
- device: "mfc.air_left_setpoint"
  value: 2.1  # Volts (typically 0-5V range)
  timing: 1000
```

### Trigger Signals

Generate precise trigger pulses for external equipment.

**Device Keys:**

- `triggers.microscope` - Single pulse triggers for microscope
- `triggers.camera_continuous` - Continuous periodic camera triggers

**Microscope Triggers:**

```yaml
# Single pulse at specified timing
- device: "triggers.microscope" 
  state: true
  timing: 30000  # Pulse occurs at 30s mark
```

**Camera Triggers:**

```yaml
# Start continuous pulses
- device: "triggers.camera_continuous"
  state: true
  timing: 1000

# Stop continuous pulses  
- device: "triggers.camera_continuous"
  state: false
  timing: 60000
```

## Sequence Definition

### Phase Structure

Each phase represents a distinct experimental period with defined duration and actions.

```yaml
- phase: "Descriptive Phase Name"
  duration: 30000        # Total phase duration in ms
  times: 5               # Number of repetitions (recommended)
  repeat: 0              # Legacy: 0=no repeat, 1=repeat once  
  randomize: true        # Randomize state order within lists
  actions:               # List of device actions
    - device: "device.name"
      state: "STATE"
      timing: 1000       # Offset within phase (ms)
```

### Action Timing

All action timing is relative to the **start of each phase repetition**.

**Example Timeline:**

```yaml
- phase: "Trial Phase"
  duration: 60000  # 60 second phase
  times: 3         # Repeat 3 times
  actions:
    - device: "olfactometer.left"
      state: "ODOR1"
      timing: 0        # At phase start: 0s, 60s, 120s
    - device: "triggers.microscope"  
      state: true
      timing: 30000    # Mid-phase: 30s, 90s, 150s
```

### Randomization

When `randomize: true` and multi-state lists are provided:

```yaml
- phase: "Randomized Odors"
  times: 4
  randomize: true
  actions:
    - device: "olfactometer.left"
      state: "ODOR1,ODOR2,ODOR3,ODOR4"  # Will be shuffled each protocol run
      timing: 0
```

The `seed` parameter in timing configuration ensures reproducible randomization.

## Advanced Features

### State Copying

The right olfactometer can mirror the left side's resolved state:

```yaml
- device: "olfactometer.left" 
  state: "ODOR1,ODOR2,ODOR3"
  timing: 0
- device: "olfactometer.right"
  state: "COPY"  # Uses same resolved state as left
  timing: 100    # Slight delay for timing control
```

### Precise Timing Control

**Hardware Constraints:**

- S-bits switch `preload_lead_ms` before LOAD_REQ pulses
- `setup_hold_samples` provide stability margins around load events
- Overlapping preload windows are detected and rejected at compile time

**Timing Guardrails:**
The compiler enforces timing constraints to prevent hardware conflicts and ensure reliable valve switching.

## Complete Example

```yaml
protocol:
  name: "Odor Discrimination Task"
  timing:
    sample_rate: 1000
    seed: 42

sequence:
  - phase: "Baseline"
    duration: 30000
    times: 1
    actions:
      - device: "olfactometer.left"
        state: "AIR"
        timing: 0
      - device: "triggers.camera_continuous"
        state: true  
        timing: 1000

  - phase: "Odor Presentation"
    duration: 60000
    times: 5
    randomize: true
    actions:
      - device: "olfactometer.left"
        state: "ODOR1,ODOR2,ODOR3,ODOR4,ODOR5"
        timing: 0
      - device: "switch_valve.left"
        state: "ODOR"
        timing: 10000
      - device: "triggers.microscope"
        state: true
        timing: 15000
```

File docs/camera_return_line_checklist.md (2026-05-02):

# Camera Return-Line Checklist

This checklist is specific to the Blackfly S BFS-U3-13Y3M camera return wiring used on this rig.

## Confirm the camera GPIO pins first

For the 6-pin Hirose GPIO cable on this camera family:

- green = pin 1 = +12 V / non-isolated input
- black = pin 2 = Line0 = opto-isolated input
- red = pin 3 = Line2 = GPIO / open-drain / optional 3.3 V rail
- white = pin 4 = Line1 = Opto Output 1
- blue = pin 5 = Opto GND
- brown = pin 6 = camera power ground

The important consequence is:

- the white wire is `Line1`, not `Line2`
- the white wire is an isolated opto output referenced to the blue wire
- `Line2` is a different pin and is reported by the live camera as `OpenDrain`

## What the live rig cameras reported

The connected BFS-U3-13Y3M cameras reported:

- `Line0`: `OptoCoupled`, input
- `Line1`: `OptoCoupled`, output
- `Line2`: `OpenDrain`, output
- `Line3`: `TriState`, input

That matches the vendor camera reference and explains why configuring `Line2 = ExposureActive` does not drive the white wire.

## Current DAQ return mapping

- `CAMERA_FRONT_O1` -> `Dev1/port0/line29` -> pin 125
- `CAMERA_SIDE_O1` -> `Dev1/port0/line27` -> pin 123

## Bench rule for white-wire tests

If you are testing the white wire, you must wire the blue `Opto GND` into the measurement circuit.

If only the white wire is connected to the NI-DAQ DI and the blue wire is left floating, the DAQ will usually read a constant low level even if the camera is toggling the internal signal correctly.

## DAQ-only electrical visibility test

Run this from the `multibios-blackfly` environment:

```powershell
python tools/manual_checks/verify_camera_return_line.py --line line1
```

This drives `Line1` through `UserOutput1` and checks whether either DAQ return line changes state.

Interpretation:

- if a DAQ line changes, the return path is electrically visible
- if neither DAQ line changes, the likely causes are missing blue `Opto GND`, missing external bias path on the isolated output, or a wiring mistake at the camera connector

## Optional red-wire test

If you intentionally wired the red wire instead of the white wire, test `Line2` instead:

```powershell
python tools/manual_checks/verify_camera_return_line.py --line line2
```

Interpretation:

- `Line2` is `OpenDrain`
- an open-drain line requires an external pull-up to generate a logic-high level
- without that pull-up, the DAQ will also read a constant low level

## Scope test for the white wire

Recommended connection:

- scope probe tip -> white wire path under test
- scope ground -> blue `Opto GND`

Do not reference the white wire to brown camera ground for the isolated-output test.

## Controlled pull-up or bias test

If the white-wire DAQ test stays flat, do one controlled bench bias test before changing software again.

Recommended pattern:

- white wire -> DAQ DI under test
- white wire -> pull-up resistor to a small external logic rail
- blue `Opto GND` -> external logic ground and DAQ ground/reference

Use a conservative pull-up such as 2.2 kOhm to 10 kOhm to a logic-level rail that is valid for the DAQ input path you are measuring.

Interpretation:

- if the line now toggles, the earlier failure was an electrical bias/reference problem, not trigger acceptance
- if it still does not toggle, the remaining suspects are wrong camera pin, wrong DAQ landing, or camera GPIO configuration on the wrong line

## Practical next bench order

1. Verify the white-wire path with `python tools/manual_checks/verify_camera_return_line.py --line line1`.
2. If it stays flat, confirm the blue `Opto GND` is actually tied into the DAQ/scope reference.
3. If it still stays flat, repeat the test with a controlled external pull-up or bias path.
4. Only test `Line2` if you are intentionally using the red wire and have provided an external pull-up.

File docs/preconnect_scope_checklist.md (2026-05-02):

# Pre-Connect Oscilloscope Checklist

Date: 2026-03-27

## Purpose

Use this checklist before connecting the NI-DAQ outputs to the Blackfly S BFS-U3-13Y3M cameras or the MFC setpoint inputs.

The goals are:

- verify the DAQ output voltages and pulse timing unloaded
- verify the mapped channels match the intended hardware lines
- reduce the risk of over-voltage, wrong polarity, or wiring mistakes before any external device is attached

This checklist is written for the current hardware map in [config/hardware.yaml](../config/hardware.yaml).

## Current channel map being tested

### Camera trigger and returns

- `TRIG_CAMERA` -> `Dev1/port0/line31` -> pin 127
- `DGND` -> pin 128
- `CAMERA_FRONT_O1` -> `Dev1/port0/line29` -> pin 125
- `CAMERA_SIDE_O1` -> `Dev1/port0/line27` -> pin 123

### MFC analog setpoints

- `mfc.air_left_setpoint` -> `Dev1/ao0`
- `mfc.air_right_setpoint` -> `Dev1/ao1`
- `mfc.odor_left_setpoint` -> `Dev1/ao2`
- `mfc.odor_right_setpoint` -> `Dev1/ao3`

### MFC analog feedback

- `mfc.air_left_flowrate` -> `Dev1/ai0`
- `mfc.air_right_flowrate` -> `Dev1/ai1`
- `mfc.odor_left_flowrate` -> `Dev1/ai2`
- `mfc.odor_right_flowrate` -> `Dev1/ai3`

## Before you start

### External devices must remain disconnected

Do not connect the following while running this checklist:

- Blackfly S camera trigger input wires
- Blackfly S camera `O1` return wires
- MFC setpoint input wires
- MFC analog feedback output wires

The point of this checklist is to validate the DAQ signals first.

### Scope setup

Recommended starting setup:

- use a x10 probe if available
- use DC coupling
- start at 1 V/div or 2 V/div for digital trigger checks
- start at 1 V/div for analog output checks
- start with a 500 ms/div or 1 s/div timebase for trigger pulse tests
- use the DAQ ground that corresponds to the signal family you are probing

### Grounding rule

Probe each signal against the correct DAQ ground reference.

For digital trigger checks:

- probe against `DGND`

For analog output checks:

- probe against the adjacent analog output ground terminal

Do not mix analog and digital grounds casually on the bench just because they are ultimately common inside the DAQ. For clean measurements, reference each signal to its intended return terminal.

## Files added for this test

### Checklist

- [docs/preconnect_scope_checklist.md](../docs/preconnect_scope_checklist.md)

### Test script

- [tools/manual_checks/preconnect_scope_test.py](../tools/manual_checks/preconnect_scope_test.py)
- [tools/manual_checks/verify_camera_return_line.py](../tools/manual_checks/verify_camera_return_line.py)

## Test 1: Verify the camera trigger output unloaded

### Test 1 checks

- trigger line is on the expected DAQ channel
- idle state is low
- pulse amplitude is correct
- pulse width is correct
- repetition period is correct

### Test 1 scope connection

- probe tip -> pin 127 (`TRIG_CAMERA`, `port0/line31`)
- probe ground -> pin 128 (`DGND`)

### Test 1 command to run

```powershell
python tools/manual_checks/preconnect_scope_test.py trigger --hardware config/hardware.yaml --period-ms 1000 --pulse-ms 10 --duration 5 --sample-rate 10000
```

### Test 1 expected result

- one pulse per second
- pulse width approximately 10 ms
- low level near 0 V
- high level appropriate for the NI-DAQ digital line
- clean square edges without obvious collapse or ringing

### Test 1 pass criteria

- pulse timing matches the command
- voltage levels are stable and repeatable
- no unexpected inverted polarity

### Test 1 fail criteria

- pulses are missing
- line is stuck high or low
- pulse width is wrong by a large amount
- voltage amplitude looks wrong for the DAQ output

## Test 2: Verify each MFC analog output unloaded

### Test 2 checks

- each AO line reaches the expected voltage
- the channel mapping is correct
- steps are clean and monotonic
- no clipping or offset error is obvious before connecting MFCs

### Test 2 waveform behavior

The script drives one AO channel at a time through a step sequence while all other AO channels remain at 0 V.

Default step sequence:

- 0.0 V
- 1.0 V
- 2.0 V
- 3.0 V
- 4.0 V
- 5.0 V
- 0.0 V

Each level is held for 1 second by default.

### Test 2 scope connection

Probe one channel at a time.

Suggested order:

1. `ao0` against AO GND
2. `ao1` against AO GND
3. `ao2` against AO GND
4. `ao3` against AO GND

### Test 2 command to run

```powershell
python tools/manual_checks/preconnect_scope_test.py analog --hardware config/hardware.yaml --dwell 1.0 --sample-rate 2000
```

### Test 2 expected result

For each AO channel in turn:

- the voltage steps through 0, 1, 2, 3, 4, 5, and back to 0 V
- other AO channels stay at or near 0 V while that channel is under test

### Test 2 pass criteria

- each commanded level appears at the correct output
- voltages are within reasonable tolerance of the target values
- channels do not appear swapped
- output returns to 0 V at the end

### Test 2 fail criteria

- wrong channel moves
- levels are clipped, shifted, or unstable
- more than one channel steps when only one should

## Test 3: Save bench notes before connecting devices

Record the following after the unloaded tests:

- trigger high level
- trigger low level
- trigger pulse width
- trigger period
- AO0 measured levels
- AO1 measured levels
- AO2 measured levels
- AO3 measured levels
- anything unexpected about noise, overshoot, or polarity

## Test 4: Connect one camera only

Do this only after Test 1 passes.

### Test 4 wiring

- Blackfly S trigger input wire -> pin 127
- Blackfly S ground/return wire -> pin 128
- leave the white wire disconnected for the first trigger-only test

### Test 4 command to run

Use the same trigger command as Test 1.

### Test 4 expected result

- the camera should respond to the external trigger
- the trigger waveform on the DAQ line should still look clean

### Test 4 pass criteria

- camera triggers reliably
- DAQ output does not collapse under load

## Test 5: Connect one camera return line

Do this only after the single-camera trigger test passes.

### Test 5 wiring

- camera white wire -> the assigned DI line
- camera blue wire -> the measurement return for the opto-isolated output
- front camera white -> pin 125
- side camera white -> pin 123

### Test 5 important note

The BFS-U3-13Y3M white wire is `Line1`, which is an opto-coupled output.
Its return reference is the blue `Opto GND` wire, not the camera power ground.

The red wire is `Line2`, which is a separate open-drain GPIO line.

Check whether the specific line under test is:

- push-pull
- open collector
- opto output
- or requires a pull-up or specific external bias

### Test 5 expected result

- once configured as `ExposureActive` or similar on the correct physical line, the camera output should generate a measurable returned pulse
- if the white wire is tested without the blue `Opto GND` reference in the circuit, the DAQ may read no transitions even when the camera is configured correctly

### Test 5 command to run

```powershell
python tools/manual_checks/verify_camera_return_line.py --line line1 --hardware config/hardware.yaml
```

If you are intentionally testing the red wire instead of the white wire:

```powershell
python tools/manual_checks/verify_camera_return_line.py --line line2 --hardware config/hardware.yaml
```

## Test 6: Connect one MFC only

Do this only after Test 2 passes.

### Test 6 order

1. connect one AO setpoint line to one MFC input
2. verify the MFC accepts the range safely
3. connect the corresponding AI feedback line
4. verify the AI trace responds on the expected channel

Do not connect all four MFCs at once for the first live test.

## Recommended bench sequence

Use this order exactly:

1. unloaded camera trigger test
2. unloaded analog output step test
3. one camera trigger test
4. one camera return test
5. one MFC setpoint test
6. one MFC feedback test
7. second camera
8. remaining MFCs

## Quick commands summary

```powershell
python tools/manual_checks/preconnect_scope_test.py trigger --hardware config/hardware.yaml --period-ms 1000 --pulse-ms 10 --duration 5 --sample-rate 10000

python tools/manual_checks/preconnect_scope_test.py analog --hardware config/hardware.yaml --dwell 1.0 --sample-rate 2000

python tools/manual_checks/preconnect_scope_test.py both --hardware config/hardware.yaml --period-ms 1000 --pulse-ms 10 --duration 5 --dwell 1.0 --sample-rate 10000

python tools/manual_checks/verify_camera_return_line.py --line line1 --hardware config/hardware.yaml
```

## Safety stop conditions

Stop immediately if any of the following happen:

- analog output exceeds expected setpoint range
- digital trigger polarity is opposite of what the camera expects
- a supposedly idle line shows unexpected switching
- multiple AO channels move when only one should
- the DAQ line voltage collapses abnormally under a connected load

## Bottom line

Do not connect the cameras or the MFCs until the unloaded scope checks pass first.

The trigger test confirms the digital camera path is electrically sane.
The analog step test confirms the MFC setpoint outputs are electrically sane.
Once both pass, connect one external device at a time and re-test under load.

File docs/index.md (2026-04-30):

# MultiBiOS Odor Delivery System

<div align="center">
  <strong>🧪 Precision Olfactometer Control for Behavioral Neuroscience 🧪</strong>
</div>

---

## Overview

**MultiBiOS** (Multispecies Bilateral Odor delivery System) is a high-precision, hardware-clocked olfactometer control system designed for behavioral neuroscience experiments. It provides sub-millisecond timing control, full signal provenance, and reproducible experimental protocols.

!!! tip "Key Features"
    - **⚡ Sub-millisecond precision** with hardware-clocked timing
    - **🔄 Bilateral control** for complex comparative experiments  
    - **📊 Full signal provenance** with comprehensive logging
    - **🛡️ Built-in guardrails** prevent timing conflicts
    - **🎲 Reproducible randomization** via configurable seeds
    - **📈 Interactive visualization** with Plotly integration

## System Architecture

The MultiBiOS system consists of three main components working in perfect synchronization:

=== "Hardware Layer"
    - **Teensy 4.1** microcontroller for valve preloading
    - **TPIC6B595** shift register chains (10MHz SPI)
    - **NI USB-6353** for hardware-clocked timing
    - **Mass flow controllers** for precise flow control

=== "Firmware Layer"  
    - **Interrupt-driven architecture** on Teensy 4.1
    - **Pattern preloading** with sticky S-bit rails
    - **Hardware synchronization** via RCK signals
    - **Safety interlocks** and state validation

=== "Software Layer"
    - **YAML protocol compiler** with timing validation
    - **Hardware-clocked execution** via NI-DAQmx
    - **Real-time logging** of all signals
    - **Interactive analysis** and visualization

## Quick Start

Get up and running with MultiBiOS in minutes:r Delivery System

**Multispecies Bilateral Odor Delivery** with sub-millisecond control and full signal provenance.

This repository provides:

- **Teensy 4.1 firmware** that preloads valve patterns and commits on **NI-DAQ register clocks** (RCK).
- A **YAML protocol** that describes stimuli, triggers, and MFC setpoints with ms-level timing.
- A **hardware-clocked NI USB-6353 runner** that generates DO/AO, and logs **MFC analog feedback** (AI).
- **Guardrails** that reject overlapping preload→commit windows at compile-time.
- **Sticky S-bit rails** so digital state lines reflect the system’s current logical state between events.
- **Interactive Plotly viewer** that overlays compiled DO/AO with captured AI.
- Reproducible **randomization** via a configurable `seed`.

## Quickstart

### 1. Preview Mode (No Hardware Required)

```bash
# Generate and visualize a protocol without hardware
poetry run python -m multibios.run_protocol \
    --yaml protocols/example_protocol.yaml \
    --hardware config/hardware.yaml \
    --dry-run --interactive --seed 42
```

### 2. Hardware Execution

```bash
# Run on actual hardware (requires NI-DAQmx drivers)
poetry run python -m multibios.run_protocol \
    --yaml protocols/example_protocol.yaml \
    --hardware config/hardware.yaml
```

### 3. Post-Run Analysis

```bash
# Visualize any completed experiment
poetry run python -m multibios.viz_protocol data/runs/2025-08-21_14-07-33
```

## What Makes MultiBiOS Special?

### 🎯 Hardware-Clocked Precision

Unlike software-based timing systems, MultiBiOS uses dedicated hardware clocks for microsecond-precise valve control, ensuring experimental reproducibility even under system load.

### 🔒 Compile-Time Safety

The protocol compiler validates all timing constraints before execution, preventing hardware conflicts and ensuring reliable operation.

### 📊 Complete Data Provenance

Every signal is logged with timestamps, providing a complete record of experimental conditions for analysis and publication.

### 🎲 Reproducible Randomization

Configurable random seeds ensure that "randomized" protocols can be exactly reproduced for validation and replication studies.

## Example Protocol

Here's a simple bilateral odor presentation protocol:

```yaml
protocol:
  name: "Bilateral Odor Test"
  timing:
    sample_rate: 1000
    seed: 42

sequence:
  - phase: "Baseline"
    duration: 30000  # 30 seconds
    times: 1
    actions:
      - device: "olfactometer.left"
        state: "AIR"
        timing: 0
      - device: "olfactometer.right"  
        state: "AIR"
        timing: 0

  - phase: "Odor Presentation"
    duration: 60000  # 1 minute
    times: 5
    randomize: true
    actions:
      - device: "olfactometer.left"
        state: "ODOR1,ODOR2,ODOR3"  # Randomized selection
        timing: 0
      - device: "triggers.microscope"
        state: true
        timing: 15000  # Trigger 15s into each trial
```

!!! success "Ready to Get Started?"
    Check out the **[Hardware Setup](hardware.md)** guide to begin building your MultiBiOS system, or explore the **[Protocol Specification](protocol.md)** to understand the YAML format.

See **Hardware** for wiring and safety, **Protocol** for YAML schema, and **Runner** for execution and logging.

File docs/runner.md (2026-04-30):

# Protocol Runner (NI-DAQ Application)

The protocol runner compiles YAML protocol files, generates **hardware-clocked digital/analog outputs**, and captures **analog input** feedback from mass flow controllers (MFCs).

## Dependencies

- **NI-DAQmx** driver and Python API (`pip install nidaqmx`)
- **Core libraries**: numpy, pyyaml, plotly (for visualization)
- **Validated environment on this rig**: `multibios-blackfly` created from `environment.yml`

## Command Line Interface

### Dry Run (Preview Only)

```bash
# Generate preview without hardware execution
conda run -n multibios-blackfly python -m multibios.run_protocol \
  --yaml protocols/example_protocol.yaml \
  --hardware config/hardware.yaml \
  --dry-run --seed 42
```

### Hardware Execution  

```bash
# Execute protocol on DAQ hardware
conda run -n multibios-blackfly python -m multibios.run_protocol \
  --yaml protocols/example_protocol.yaml \
  --hardware config/hardware.yaml
```

If `hardware.yaml` contains a `fictrac:` block, the runner will also launch FicTrac, wait for the first UDP frame, and save FicTrac artifacts into the same run directory.

## Command Line Options

### Core Arguments

- `--yaml <file>`: Protocol YAML file (default: `protocols/example_protocol.yaml`)
- `--hardware <file>`: Hardware mapping YAML (default: `config/hardware.yaml`)
- `--experiment <file>`: Optional runtime override file for backward-compatible experiment/camera/FicTrac settings
- `--device <name>`: Override DAQ device name from hardware.yaml
- `--dry-run`: Compile and preview only, no hardware execution
- `--out-root <dir>`: Output directory root (default: `data/runs`)

### Timing Overrides

- `--seed <int>`: Override `protocol.timing.seed` for reproducible randomization
- `--preload-lead-ms <int>`: Override preload lead time
- `--load-req-ms <int>`: Override load request pulse duration  
- `--rck-ms <int>`: Override register clock pulse duration
- `--trig-ms <int>`: Override trigger pulse duration

### Visualization

- `--interactive`: Always save interactive HTML preview (even without `--dry-run`)

### Logging & Progress

- `--verbose` / `-v`: Enable verbose logging with detailed progress information
- `--debug`: Enable debug logging (extremely detailed, for troubleshooting)
- `--progress`: Enable real-time progress monitor during protocol execution
- `--progress-interval <ms>`: Set progress update interval in milliseconds (default: 100)

## Real-Time Progress Monitoring

The protocol runner now supports **real-time progress monitoring** during hardware execution. This displays the expected protocol state while the DAQ is running, helping you track what should be happening at each moment.

### Enabling Progress Monitor

```bash
conda run -n multibios-blackfly python -m multibios.run_protocol \
  --yaml protocols/example_protocol.yaml \
  --hardware config/hardware.yaml \
  --verbose \
  --progress \
  --progress-interval 100
```

### What It Shows

During execution, you'll see periodic updates like:

```text
[  5.0%] [t=250.0ms] DO: RCK=LOW, LOAD_REQ=HIGH, S0=LOW | AO: MFC1=2.500V, MFC2=1.200V
[ 10.0%] [t=500.0ms] DO: RCK=HIGH, LOAD_REQ=LOW, S0=HIGH | AO: MFC1=3.000V, MFC2=1.500V
[ 15.0%] [t=750.0ms] DO: RCK=LOW, LOAD_REQ=LOW, S0=LOW | AO: MFC1=2.500V, MFC2=1.200V
```

Each update includes:

- **Progress percentage**: How far through the protocol
- **Timestamp**: Current protocol time in milliseconds
- **Digital outputs (DO)**: State of key digital lines (HIGH/LOW)
- **Analog outputs (AO)**: Voltage levels of analog channels

### Customizing Updates

- **Update frequency**: Use `--progress-interval <ms>` to control how often updates appear
  - Lower values (e.g., 50ms) = more frequent updates, more detailed tracking
  - Higher values (e.g., 500ms) = less frequent updates, cleaner output
- **Which channels to show**: The monitor automatically shows the first 3 DO lines and first 2 AO channels. Full data is still recorded; this is just for display.

### When to Use

- **Long protocols**: Essential for protocols lasting several seconds or minutes
- **Debugging**: Verify that the protocol is executing as expected
- **User feedback**: Provide reassurance during execution (especially important when no visual indicators are available)
- **Troubleshooting**: Identify at what point in the protocol issues occur

### Performance Impact

The progress monitor runs in a **background thread** and has minimal performance impact:

- Does not interfere with hardware timing
- Updates are calculated from elapsed time, not polling the DAQ
- Very low CPU overhead (~0.1% on typical systems)

- `--interactive`: Always save interactive HTML preview (enabled by default)

## DAQ Clocking Architecture

- **Digital Output (DO)**: Master clock - provides `SampleClock` and `StartTrigger`
- **Analog Output (AO)**: Slave - synchronized to DO clock
- **Analog Input (AI)**: Slave - synchronized to DO clock for MFC feedback capture

## Output Files

Each run creates a timestamped directory in `data/runs/YYYY-MM-DD_HH-MM-SS/`:

- `preview.html`: Interactive Plotly visualization
- `compiled_do.npz`: Digital output arrays
- `compiled_ao.npz`: Analog output arrays  
- `capture_ai.npz`: Analog input data (if hardware run)
- `capture_di.npz`: Digital input captures from READY, camera, and other return lines (if hardware run)
- `control_plan.csv`: Shared compiled logical event schedule used by both runner paths
- `do_map.json`, `ao_map.json`: Channel mapping information
- `di_map.json`: Digital input channel mapping information
- `rck_edges.csv`: Register clock commit timestamps
- `digital_edges.csv`: All digital signal edge transitions
- `protocol.yaml`, `hardware.yaml`: Input file copies
- `meta.json`: Run metadata and parameters

If `hardware.yaml -> teensy.capture_serial: true` is enabled, the run directory also includes:

- `teensy_serial_transcript.jsonl`: Raw line-oriented USB serial transcript captured from the open-loop Teensy during the run

When FicTrac is enabled, the same directory also includes:

- `fictrac_runtime_config.txt`: exact runtime config passed to FicTrac
- `fictrac_runtime.json`: summary of runtime config edits
- `fictrac_driver_diagnostics.json`: launch and first-packet diagnostics
- `fictrac_frames.npz`: internal MultiBiOS FicTrac frame store
- `fictrac-*.dat`: native FicTrac output

## Post-Run Visualization

Use the visualization tool to re-analyze saved runs:

```bash
# Re-visualize a completed run
conda run -n multibios-blackfly python -m multibios.viz_protocol data/runs/2025-08-21_16-25-26
```

This generates an updated `preview.html` with the same device-grouped visualization as the runner.

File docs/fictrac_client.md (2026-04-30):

# FicTrac Client Architecture

This page documents the in-repo MultiBiOS FicTrac client, the frame-storage model, the closed-loop consumer API, and the validation criteria required before the older pybmt-based path can be considered deprecated.

## Why This Exists

MultiBiOS still depends on the FicTrac executable for the tracking algorithm itself, but it no longer needs an external Python wrapper to:

- launch the FicTrac subprocess
- bind the localhost UDP socket
- parse FicTrac UDP messages
- expose latest-frame access to the experiment runner

That wrapper logic now lives inside MultiBiOS so the runtime path, buffering policy, and future closed-loop semantics are all controlled in one codebase.

## Module Layout

### `multibios/fictrac_client.py`

Owns the transport and storage primitives:

- `FicTracState`: full parsed UDP state matching the upstream FicTrac variable set
- `FicTracFrame`: per-frame record used by the runner and saved outputs
- `FicTracFrameStore`: structured frame retention for logging and control
- `FicTracDriver`: subprocess + UDP receiver

### `multibios/fictrac_consumer.py`

Owns the closed-loop consumption policy:

- `ClosedLoopFrameConsumer`: newest-frame oriented consumer for loops slower than camera rate

### `multibios/experiment.py`

Owns the experiment-side integration:

- `ExperimentCallback`: callback that writes into the frame store
- `make_consumer()`: convenience constructor for future closed-loop logic

## Design Goals

The internal client was designed around four constraints.

1. Transport overhead should stay small relative to FicTrac and camera acquisition.
2. Long runs should avoid retaining all frames as Python objects.
3. Saved outputs should retain the full upstream FicTrac state for future debugging.
4. Closed-loop code must be able to read the newest state without falling behind forever.
5. The replacement must be testable against the older pybmt parser before deprecation.

## Frame Storage Model

`FicTracFrameStore` uses two storage strategies at the same time.

### 1. Full-run structured storage

All frames are retained in structured NumPy arrays with dtype `FICTRAC_FRAME_DTYPE`.

The stored record now includes the full upstream FicTrac variable set, including:

- delta rotation vectors in camera and lab coordinates
- delta rotation error
- absolute orientation vectors in camera and lab coordinates
- integrated position, heading, direction, speed, and timestamps
- UDP sequence number and optional v2.1.1 alternate timestamp

Storage is chunked in memory:

- a current writable chunk
- a list of completed chunks
- final concatenation only when a full export is requested

This is more efficient than storing one Python object per frame, but it is still an in-memory strategy.

### 2. Recent-history ring buffer

A second fixed-size ring stores the most recent frames for short-horizon filtering or control logic.

That gives closed-loop code fast access to recent history without copying the entire run.

## Important Clarification About "Chunking"

Yes, MultiBiOS is already chunking FicTrac storage now.

But it is currently:

- **chunked in memory**
- **not streamed to disk incrementally during the run**

Those are different things.

Current behavior:

- frames accumulate in numeric chunks in RAM
- at save time, they are exported to `fictrac_frames.npz`

Not yet implemented:

- periodic spill-to-disk while the run is still active
- memory-mapped backing store
- append-only binary logging during acquisition

For the current scale, in-memory chunking is the right first optimization. If future runs become long enough that total frame count becomes the dominant memory cost, then incremental disk logging is the next step.

## Closed-Loop Consumer API

`ClosedLoopFrameConsumer` is the policy layer intended for future behavior-dependent loops.

The most important methods are:

- `snapshot_latest()`
- `consume_latest()`
- `wait_for_newer(timeout=...)`
- `recent_history(max_count=...)`

### Why newest-frame semantics matter

At 200 fps, the incoming frame period is 5 ms.

If a closed-loop control cycle takes longer than 5 ms, then trying to process every frame creates backlog. The right default behavior is usually:

1. wait until something newer exists
2. consume the newest available frame
3. skip stale intermediate frames

That is exactly what `wait_for_newer()` is meant to support.

### Example pattern

```python
consumer = experiment_callback.make_consumer(start_at_latest=True)

while running:
    sample = consumer.wait_for_newer(timeout=0.02)
    if sample.frame is None:
        continue

    frame = sample.frame
    # Run the control calculation on the newest frame available.
    # If several frames arrived while the loop was busy, backlog is skipped.
    control_step(frame)
```

### Recent history example

```python
history = consumer.recent_history(max_count=8)
```

That pattern is intended for short filters, velocity smoothing, or prediction over the last few received frames.

## Validation Requirements Before Deprecating The Older Path

The internal client should not be treated as a full replacement just because it compiles or because one live probe succeeds.

The required validation surface is:

1. **Parser equivalence**: for the FicTrac UDP message formats you actually receive, the MultiBiOS parser must match pybmt on all fields MultiBiOS consumes.
2. **Frame-order behavior**: skipped-frame detection and monotonic frame counting must behave the same way.
3. **Live callback behavior**: the internal client must receive live frames on the triggered Blackfly path.
4. **Legacy-runner behavior**: the deprecated serial runner must remain stable with the internal client until it is removed.
5. **Saved-data fidelity**: exported data must contain the same tracked information needed for downstream analysis.

## What Is Tested In-Repo

The current automated tests cover:

- parser equivalence against pybmt for both 24-field and 25-field message formats across the full upstream field set
- frame-store latest-frame behavior
- frame-store wait-for-next behavior
- NPZ save/load roundtrip of structured frames
- closed-loop consumer newest-frame semantics
- experiment callback integration with the consumer

These tests are necessary, but they are not the whole deprecation bar because they do not replace live hardware validation.

## Recommended Live Validation Before Deprecation

Use this order:

1. Run the existing live triggered probe with the internal client.
2. Compare parsed values from the internal path and the older pybmt path on the same captured UDP payloads if you still have the older environment available.
3. Run the bounded legacy serial-runner procedure from [legacy/serial_experiment_pipeline.md](legacy/serial_experiment_pipeline.md).
4. Compare frame counts, timestamps, and saved tracking columns across both paths.
5. Only then remove or formally deprecate the old wrapper path.

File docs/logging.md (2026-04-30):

# Logging & Artifacts

Each run creates a folder: `data/runs/YYYY-MM-DD_HH-MM-SS/` with:

- `meta.json`: device, sample rate, duration, **rng_seed**, CLI args.
- `protocol.yaml`, `hardware.yaml`: copies of inputs for provenance.
- `do_map.json`, `ao_map.json`: logical names → physical channels.
- `di_map.json`: digital input channel map for READY and camera return lines.
- `compiled_do.npz`: boolean array `[lines, samples]`.
- `compiled_ao.npz`: float array `[channels, samples]`.
- `capture_ai.npz`: (optional) float array `[channels, samples]` with MFC feedback.
- `capture_di.npz`: (optional) boolean array `[lines, samples]` with recorded digital inputs.
- `control_plan.csv`: shared compiled logical schedule written by both `run_protocol` and `experiment`.
- `rck_edges.csv`: planned commits (`signal, sample_idx, time_ms`).
- `digital_edges.csv`: **all** rising/falling edges for every DO line.
- `preview.html`: interactive Plotly visualization.

If `hardware.yaml` enables `teensy.capture_serial: true`, the same folder also includes:

- `teensy_serial_transcript.jsonl`: line-oriented Teensy USB serial transcript captured alongside the run.

> You can parse `digital_edges.csv` to compute inter-event latencies and export tabular summaries alongside imaging data.

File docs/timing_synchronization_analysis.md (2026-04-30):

# Timing Synchronization Analysis

Date: 2026-03-20

## Goal

Bring NI-DAQ latch timing, triggers, Teensy-controlled valve state, FicTrac, and MFC activity onto the same timebase as precisely as possible.

## Current architecture

There are effectively two timing models in this repository.

### 1. Hardware-clocked NI-DAQ path

The NI-DAQ runner is already designed around a shared hardware clock:

- DO is the master clock.
- AO and AI can be slaved to the DO sample clock.
- Trigger pulses and latch edges can be precomputed and emitted deterministically.

This is the architecture that can support a real common timebase.

### 2. Mixed-clock experiment path

The open-loop experiment runner currently mixes:

- NI-DAQ finite DO for camera/microscope triggers and periodic latch pulses.
- Teensy serial commands issued from the host on `time.perf_counter()`.
- Alicat serial setpoints issued from the host.
- FicTrac frames timestamped by host arrival time in the callback.

This means the DAQ has a precise hardware clock, but the rest of the system is only approximately aligned to it.

### 3. DAQ-driven Teensy latch firmware path

There is also a better Teensy architecture available: the Teensy can operate purely as a DAQ-driven preload and latch slave.

In that mode:

- DAQ drives all S lines.
- DAQ drives `GLOBAL_LOAD`.
- DAQ drives each `RCK` line.
- Teensy samples the DAQ-provided state bits on `GLOBAL_LOAD`.
- Teensy shifts the SPI frame internally.
- the external hardware changes state only on the DAQ-driven `RCK` edge.
- Teensy exposes `READY_*` lines that can be measured by the DAQ.

This path is sufficient for Teensy synchronization, because the Teensy is no longer acting as an independent timebase. The authoritative physical event time becomes the DAQ latch edge.

## Main timing problems

### A. Teensy serial is not on the DAQ clock

In the current mixed runner, valve state changes are sent over USB serial from Windows at scheduled wall-clock times. That introduces host scheduling jitter, USB serial latency, and software timing error.

The Teensy command send time is therefore not the same thing as the physical valve switch time.

This problem goes away if the DAQ-driven Teensy firmware is used and runtime serial timing is removed from the valve path.

### B. Latch timing is periodic, not event-specific

The DAQ waveform currently emits periodic `GLOBAL_LOAD_REQ` and `RCK_*` pulses. That means a newly staged Teensy pattern does not appear on hardware immediately; it appears on the next latch edge.

This adds variable latency up to one full latch period.

Example consequence:

- if `latch_interval_ms = 10`, the physical switch can be delayed by anything between 0 and 10 ms after the host serial command.

### C. Software `t0` does not define true DAQ time zero

In the mixed runner, the DAQ task is started before experiment `t0` is defined from `time.perf_counter()`. That means software timestamps and DAQ waveform time are only approximately aligned.

### D. Alicat serial cannot be made truly synchronous with DAQ

If MFC setpoints are sent via serial commands, they do not share the DAQ sample clock. They can be logged and characterized, but not made precisely synchronous in the same way as DAQ AO.

### E. FicTrac callback time is not a hardware timestamp

The current FicTrac log uses host callback arrival times. That is useful for analysis, but it is not the same as the hardware time of camera exposure.

If the goal is a common timebase, frame timing must be tied to camera trigger and/or exposure signals measured by the DAQ.

## What can actually share one precise timebase

The following can be made truly common-clock if routed through the DAQ:

- digital outputs
- analog outputs
- analog inputs
- digital input markers
- counter/timestamp measurements
- camera trigger timing
- valve commit timing
- MFC setpoint timing, if driven from AO

The following cannot be truly common-clock while controlled live from the PC over serial:

- Teensy command issue time from Windows
- Alicat serial setpoint issue time
- FicTrac callback arrival time on the host

## Recommended synchronization strategy

## Recommendation 1: Make NI-DAQ the single runtime clock

This should be the core design rule.

Use the DAQ as the only authoritative experiment clock during acquisition. Anything timing-critical should either be generated directly by the DAQ or measured back by the DAQ.

## Recommendation 2: Treat Teensy as a preload device, not a timebase

The Teensy is well-suited to preloading shift-register patterns, but not as a shared precision clock if commands are sent live over USB serial from the host.

Best use of Teensy here:

- have the DAQ drive all state-select lines
- let DAQ `LOAD_REQ` and `RCK` define the actual commit instant
- let the Teensy translate those state bits into SPI preload data
- expose `READY_*` back to DAQ DI so preload completion is measured on the DAQ clock

The physical event of interest should be the DAQ-controlled commit edge, not the host serial send time.

### Teensy-specific sufficiency condition

The DAQ-driven Teensy path is sufficient for synchronization if all of the following hold:

- no live host serial commands are required to define valve timing during the run
- the DAQ sets S-bit values before `GLOBAL_LOAD`
- the LOAD-to-RCK interval is conservatively larger than Teensy ISR plus SPI transfer time
- `READY_*` is either measured or at least validated before the corresponding `RCK`

Under those conditions, the Teensy is synchronized strongly enough for the valve path.

## Recommendation 3: Replace periodic latch pulses with event-specific latch scheduling

For precision work, free-running latch pulses should be removed from the mixed path.

Instead:

- compile each intended valve change into a specific DAQ `LOAD_REQ` and `RCK` event
- send Teensy preload sufficiently early
- use the DAQ waveform to commit at the exact requested time

This removes the variable 0 to `latch_interval_ms` latency.

## Recommendation 4: Move MFC timing-critical control to DAQ AO

If the requirement is same-timebase precision, MFC setpoints should be generated by DAQ AO, with AI capturing feedback on the same sample clock.

This is the cleanest architecture for MFC synchronization.

If Alicat serial must remain in use, then it should be treated as a supervisory or slow-control path, not a precision-timed path.

## Recommendation 5: Tie camera and FicTrac timing to hardware signals

To align FicTrac to the experiment clock precisely:

- drive camera trigger from DAQ
- record camera exposure or strobe output back into DAQ DI or a counter input
- align FicTrac frame numbers to those exposure timestamps

Without exposure feedback, FicTrac timing is only approximately aligned through host processing time.

## Recommendation 6: Measure real hardware timing, not just scheduled intent

Add DAQ-recorded markers for:

- camera exposure or strobe
- Teensy `READY_*`
- optional Teensy sync pulse
- optional microscope returned trigger or frame-ack pulse

This gives post hoc verification of actual timing relationships.

## Recommendation 7: Distinguish commanded time from physical response time

Even in a fully synchronized design, not every subsystem responds instantaneously.

Examples:

- a DAQ trigger can define camera command time exactly, but actual exposure timing is best verified with a returned strobe or exposure signal
- a DAQ AO waveform can define MFC setpoint command time exactly, but actual flow still depends on MFC control dynamics and tubing dead volume
- a DAQ `RCK` edge can define valve commit time exactly, but odor arrival at the animal still depends on pneumatic transport delay

The timebase can be unified even when physical response is delayed, as long as those delayed responses are measured against the same DAQ clock.

## Practical target architecture
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

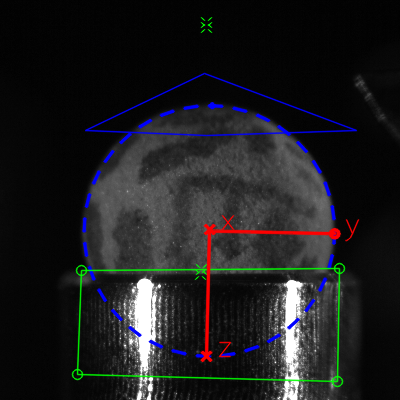
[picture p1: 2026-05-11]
fictrac-configImg.png

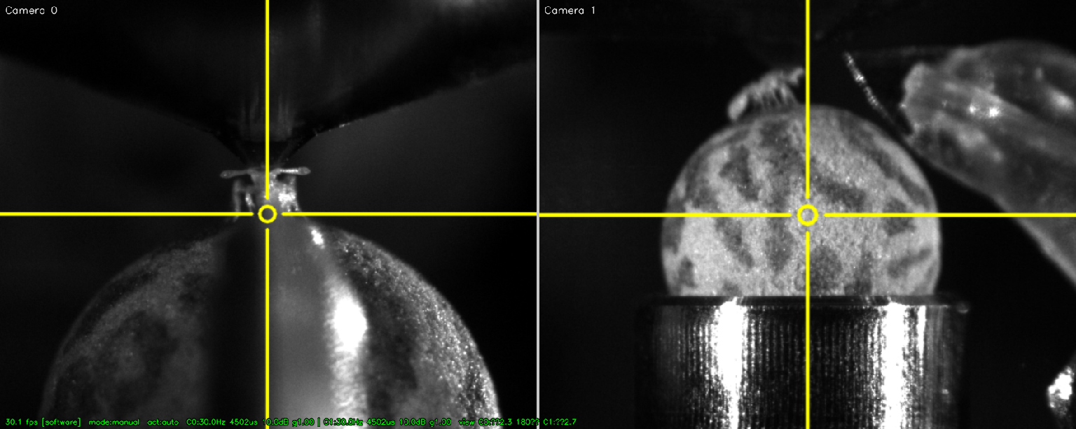
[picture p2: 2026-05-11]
Dual Flea Camera - synchronized_screenshot_08.05.2026.png

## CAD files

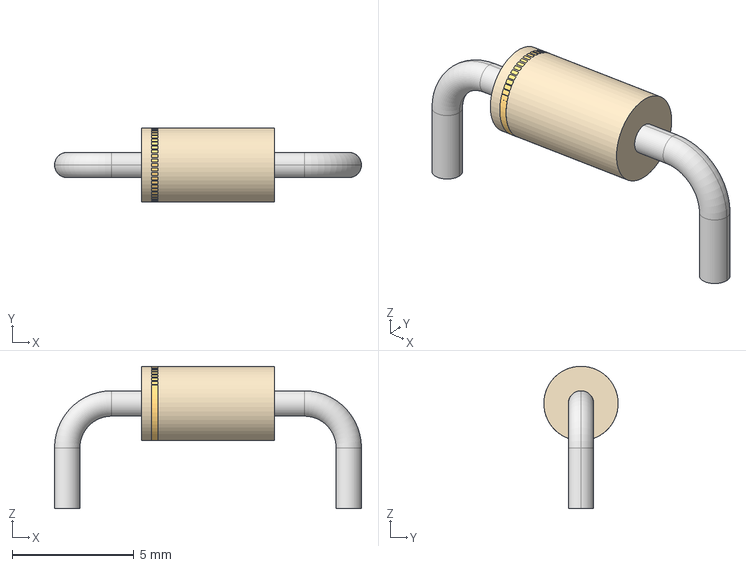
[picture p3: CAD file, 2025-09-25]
rig/electrical/SerialIndicationTerminator/parts/1N4757A/DIODE_AFL-W2Y1_8D_MOT.step
12.6 x 3.05 x 5.84 mm

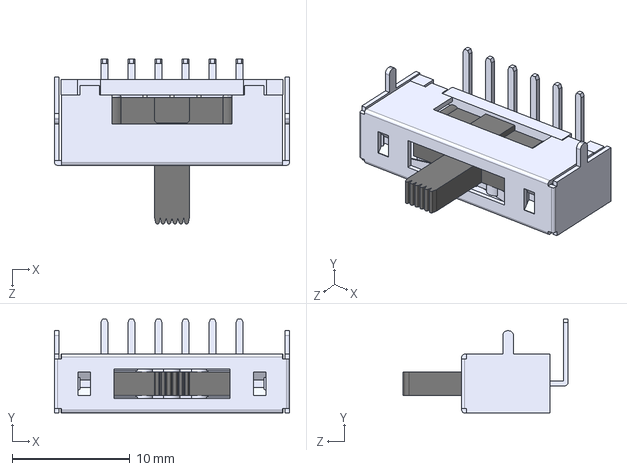
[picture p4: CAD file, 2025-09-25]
rig/electrical/SerialIndicationTerminator/parts/ASLB1470R/ASLB1470R.stp
20.0 x 8.00 x 14.0 mm

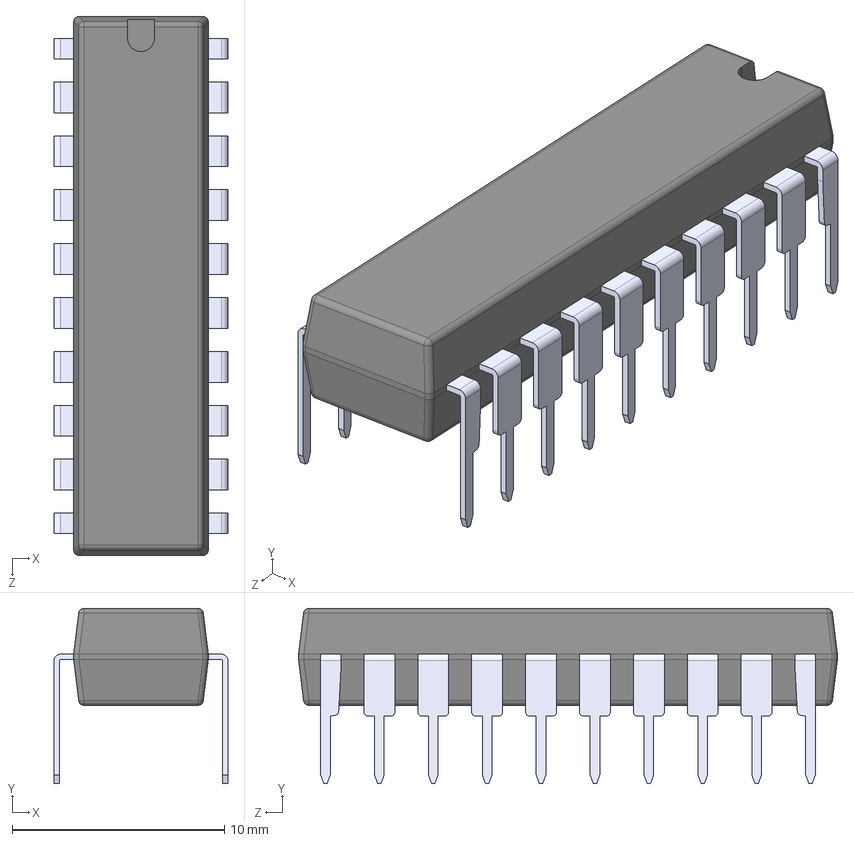
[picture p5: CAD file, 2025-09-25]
rig/electrical/SerialIndicationTerminator/parts/TPIC6B595N/TPIC6B595N.step
8.19 x 8.26 x 25.4 mm

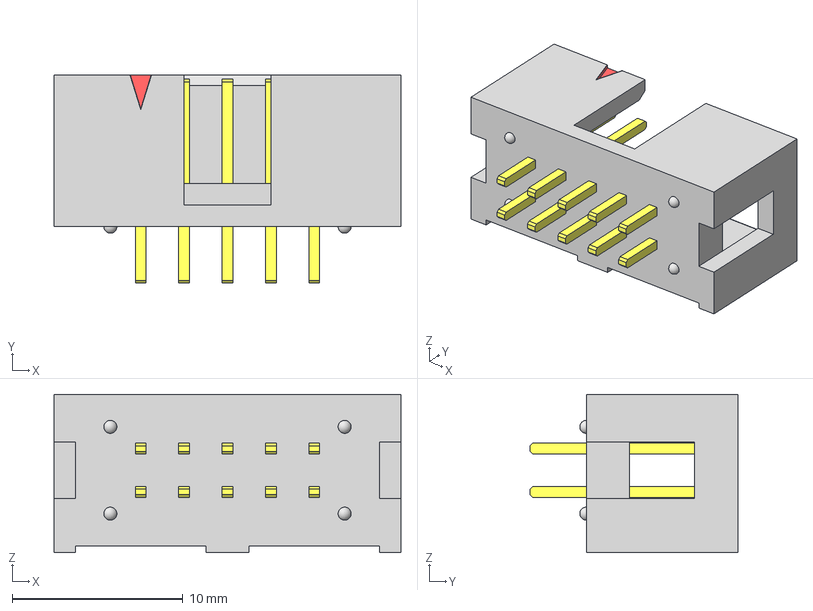
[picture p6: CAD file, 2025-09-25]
rig/electrical/SerialIndicationTerminator/parts/TST_105_01_G_D/TST-105-01-X-D.step
20.3 x 12.2 x 9.27 mm
TST-105-01-D_header
TST-First_Position_Indicator
T-1S6-05-01-D

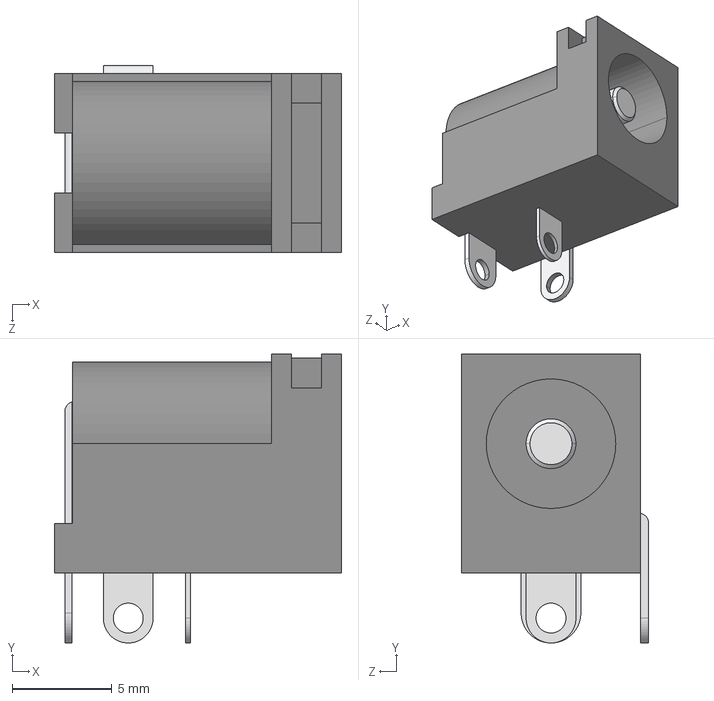
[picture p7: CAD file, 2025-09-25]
rig/electrical/TeensyOpenLoop/parts/connectors/PJ_002B/PJ-002B.STEP
14.4 x 14.5 x 9.40 mm

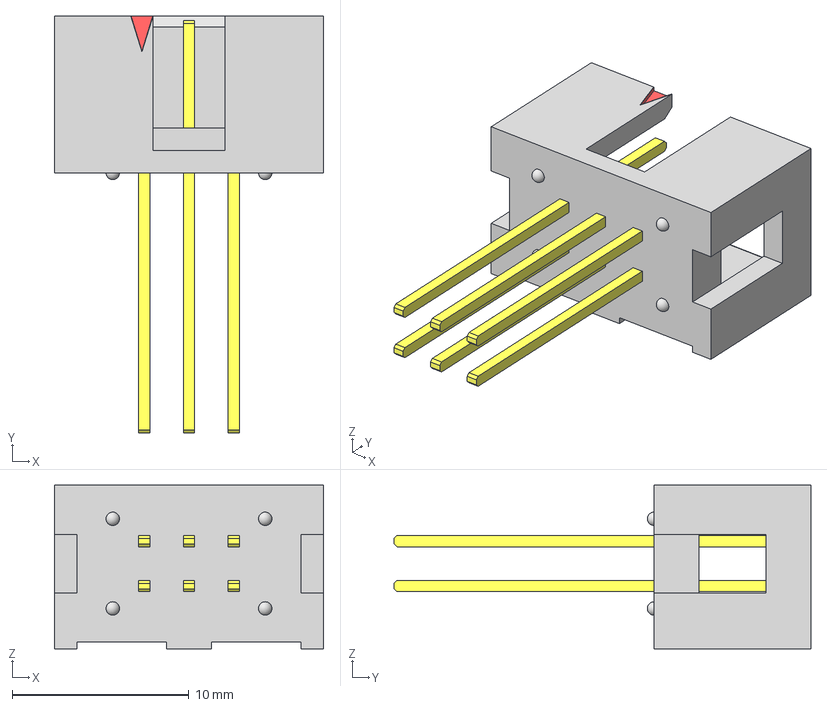
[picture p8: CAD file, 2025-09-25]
rig/electrical/TeensyOpenLoop/parts/connectors/TST/TST-103-03-T-D/TST-103-03-T-D.stp
15.2 x 23.6 x 9.27 mm
TST-103-03-D_header
TST-First_Position_Indicator
T-1S6-03-03-D

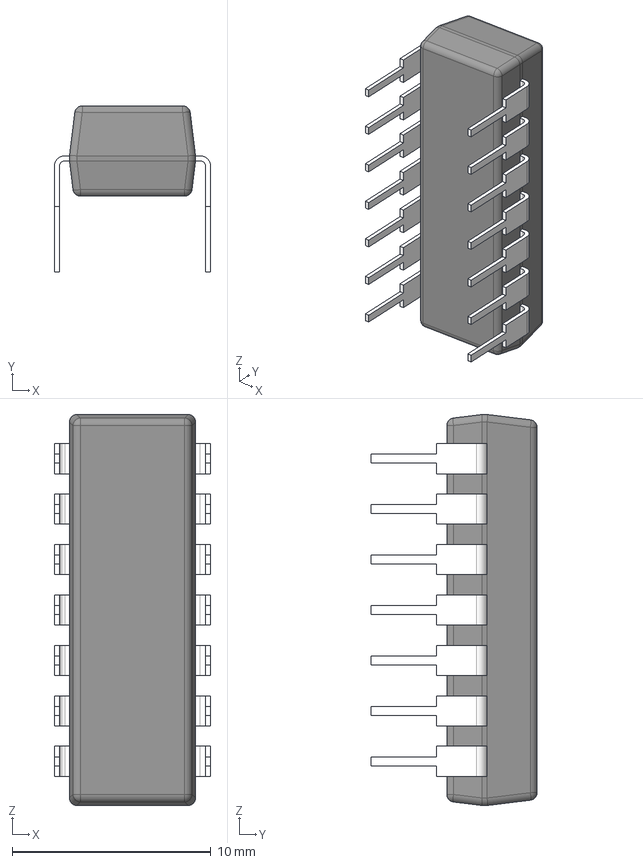
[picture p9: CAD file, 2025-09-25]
rig/electrical/TeensyOpenLoop/parts/ul_SN74AHCT125N/N0014A.stp
7.87 x 8.37 x 19.7 mm
BODY_N0014A_AF0
LEAD_N0014A_AF1
LEAD_N0014A x 10
LEAD_N0014A_AF3
LEAD_N0014A_AF0
LEAD_N0014A_AF2

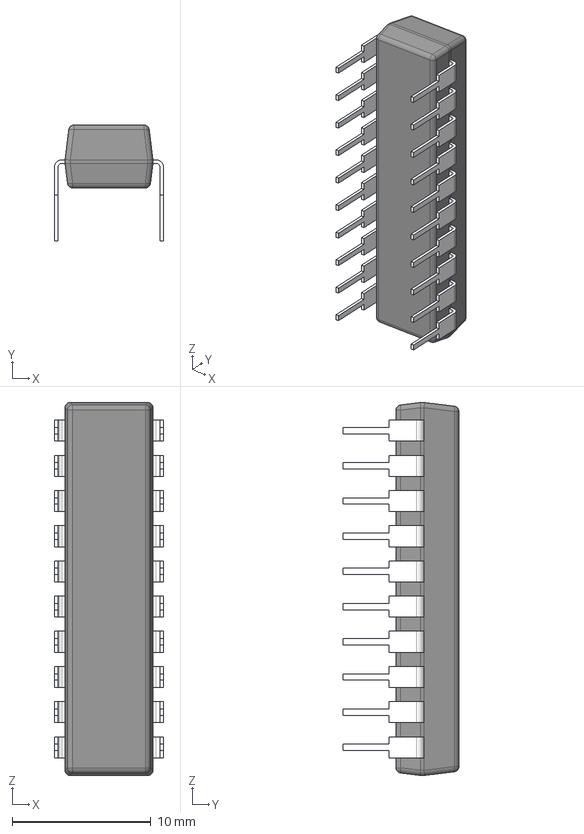
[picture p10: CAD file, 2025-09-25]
rig/electrical/TeensyOpenLoop/parts/ul_SN74LVC245AN/N0020A.stp
7.87 x 8.37 x 26.9 mm
BODY_N0020A_AF0
LEAD_N0020A_AF1
LEAD_N0020A x 16
LEAD_N0020A_AF3
LEAD_N0020A_AF0
LEAD_N0020A_AF2

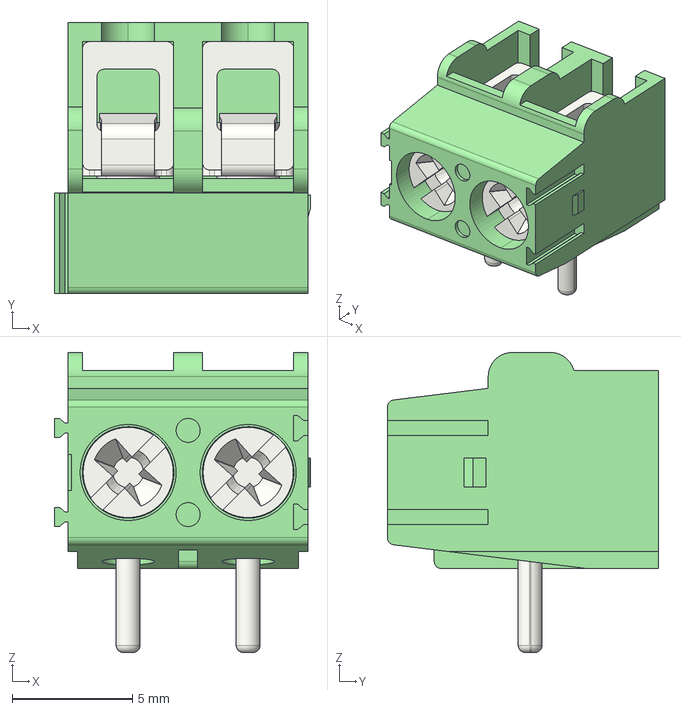
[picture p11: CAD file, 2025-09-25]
rig/electrical/SerialIndicationTerminator/parts/1935310/1935310.stp
10.7 x 11.3 x 12.5 mm

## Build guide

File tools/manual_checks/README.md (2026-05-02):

# Manual Checks

This directory contains operator-facing hardware scripts and one-off bench utilities that are meant to be run directly, not collected by `pytest`.

Typical examples:

- `mfc_analog_test.py` for MFC monitor and sweep checks
- `continuous_camera_trigger.py` and `verify_camera_trigger_path.py` for camera trigger validation
- `preconnect_scope_test.py` and `verify_camera_return_line.py` for bench wiring checks
- `fictrac_live_probe.py` for live FicTrac probing
- `hardware_test.py` for broad DAQ output validation

Use the PowerShell wrappers in [tools](../) when available:

- [run_mfc_test.ps1](../run_mfc_test.ps1)
- [run_fictrac_probe.ps1](../run_fictrac_probe.ps1)
- [run_fictrac_config_gui.ps1](../run_fictrac_config_gui.ps1)
- [run_valve_test.ps1](../run_valve_test.ps1)

The `tests` directory is now reserved for automated `pytest` coverage.

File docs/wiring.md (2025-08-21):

# Hardware Wiring & Pin Configuration

This document describes the electrical connections between the NI DAQ system and the Teensy 4.1 microcontroller for valve control.

## DAQ Channel Mapping

Configure your DAQ channels in `config/hardware.yaml`:

```yaml
device: "Dev1"
digital_outputs:
  OLFACTOMETER_LEFT_S0:        "Dev1/port0/line0"
  OLFACTOMETER_LEFT_S1:        "Dev1/port0/line1"
  OLFACTOMETER_LEFT_S2:        "Dev1/port0/line2"
  OLFACTOMETER_LEFT_LOAD_REQ:  "Dev1/port0/line3"
  RCK_OLFACTOMETER_LEFT:       "Dev1/port0/line4"
  OLFACTOMETER_RIGHT_S0:       "Dev1/port0/line5"
  OLFACTOMETER_RIGHT_S1:       "Dev1/port0/line6"
  OLFACTOMETER_RIGHT_S2:       "Dev1/port0/line7"
  OLFACTOMETER_RIGHT_LOAD_REQ: "Dev1/port0/line8"
  RCK_OLFACTOMETER_RIGHT:      "Dev1/port0/line9"
  SWITCHVALVE_LEFT_S:          "Dev1/port0/line10"
  SWITCHVALVE_LEFT_LOAD_REQ:   "Dev1/port0/line11"
  RCK_SWITCHVALVE_LEFT:        "Dev1/port0/line12"
  SWITCHVALVE_RIGHT_S:         "Dev1/port0/line13"
  SWITCHVALVE_RIGHT_LOAD_REQ:  "Dev1/port0/line14"
  RCK_SWITCHVALVE_RIGHT:       "Dev1/port0/line15"
  TRIG_MICRO:                  "Dev1/port0/line16"
  TRIG_CAMERA:                 "Dev1/port0/line17"

analog_outputs:
  mfc.air_left_setpoint:   "Dev1/ao0"
  mfc.air_right_setpoint:  "Dev1/ao1"
  mfc.odor_left_setpoint:  "Dev1/ao2"
  mfc.odor_right_setpoint: "Dev1/ao3"

analog_inputs:
  mfc.air_left_flowrate:   "Dev1/ai0"
  mfc.air_right_flowrate:  "Dev1/ai1"
  mfc.odor_left_flowrate:  "Dev1/ai2"
  mfc.odor_right_flowrate: "Dev1/ai3"
```

## Teensy 4.1 Pin Configuration

**SPI Communication:**

- MOSI = Pin 11
- SCK = Pin 13

**RCK Sense Inputs (from DAQ):**

- Olfactometer Left = Pin 2
- Olfactometer Right = Pin 3  
- Switch Valve Left = Pin 4
- Switch Valve Right = Pin 5

**Ready Signal Outputs (optional monitoring):**

- Olfactometer Left = Pin 6
- Olfactometer Right = Pin 7
- Switch Valve Left = Pin 8  
- Switch Valve Right = Pin 9

**State Input Pins (from DAQ):**

- Olfactometer Left: S0=Pin 14, S1=Pin 15, S2=Pin 16
- Olfactometer Right: S0=Pin 17, S1=Pin 18, S2=Pin 19
- Switch Valve Left: S=Pin 20
- Switch Valve Right: S=Pin 21

**Load Request Inputs (from DAQ):**

- Olfactometer Left = Pin 22
- Olfactometer Right = Pin 23
- Switch Valve Left = Pin 24
- Switch Valve Right = Pin 25

**Wiring Notes:**

- Connect DAQ RCK output lines to corresponding Teensy RCK sense inputs
- Keep all grounds common between DAQ and Teensy
- Use level shifters if DAQ outputs 5V (Teensy inputs are 3.3V tolerant)
- Label panel connections with descriptive names (not A/B/C/D)

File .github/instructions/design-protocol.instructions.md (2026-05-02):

---
applyTo: "config/**/*.yaml"
---

# Designing MultiBiOS Protocol YAML Files

## Canonical File Template

```yaml
# ==============================================================
#  PROTOCOL NAME
#  Brief description of what conditions are being tested.
#
#  ┌─────────────────────────────────────────────────────┐
#  │  CHANGE THE ODOR HERE (one place, applies to all)   │
#  │  Options: ODOR1  ODOR2  ODOR3  ODOR4  ODOR5  FLUSH  │
#  └─────────────────────────────────────────────────────┘
_active_odor: &odor "ODOR1"
_mfc_odor_flow_slpm: &mfc_flow 0.03
# ==============================================================

protocol:
  name: "Protocol Name"
  version: "1.0"
  description: >
    One-paragraph description of the experiment.

  timing:
    base_unit: "ms"
    sample_rate: 1000            # Hz — 1 ms precision (use 10000 for 0.1 ms)
    preload_lead_ms: 2           # S-bit setup lead time
    load_req_ms: 1
    rck_pulse_ms: 1
    trig_pulse_ms: 5
    setup_hold_samples: 100
    load_mode: "global"          # "global" (recommended) or "per_assembly"
    seed: 42                     # Include if using randomized state selection

sequence:
  - phase: "BOOT SEQUENCE"       # Always first
    ...

  - phase: "OLFACTOMETER SATURATION"   # Always second (60 s drain/fill)
    ...

  # --- trials here ---

  - phase: "OLFACTOMETER DESATURATION" # Always second-to-last
    ...

  - phase: "SHUTDOWN SEQUENCE"   # Always last
    ...
```

---

## Required Phase Order

Every protocol must include these phases in this order:

### 1. BOOT SEQUENCE (always ≥ 11 000 ms)
```yaml
- phase: "BOOT SEQUENCE"
  duration: 11000
  repeat: 0
  actions:
    - device: "mfc.air_left_setpoint"
      value: *mfc_flow
      timing: 1000
    - device: "mfc.air_right_setpoint"
      value: *mfc_flow
      timing: 1000
    - device: "mfc.odor_left_setpoint"
      value: *mfc_flow
      timing: 1000
    - device: "mfc.odor_right_setpoint"
      value: *mfc_flow
      timing: 1000
    - device: "triggers.camera_continuous"
      state: true
      timing: 1000
    - device: "olfactometer.left"
      state: "AIR"
      timing: 1000
    - device: "olfactometer.right"
      state: "AIR"
      timing: 1005                # +5 ms offset to avoid simultaneous register writes
    - device: "switch_valve.left"
      state: "CLEAN"
      timing: 1010
    - device: "switch_valve.right"
      state: "CLEAN"
      timing: 1015
```

### 2. OLFACTOMETER SATURATION (always 65 000 ms)
```yaml
- phase: "OLFACTOMETER SATURATION"
  duration: 65000
  repeat: 0
  actions:
    - device: "olfactometer.left"
      state: *odor
      timing: 0
    - device: "olfactometer.right"
      state: *odor
      timing: 5
    - device: "switch_valve.left"
      state: "CLEAN"
      timing: 0
    - device: "switch_valve.right"
      state: "CLEAN"
      timing: 0
    - device: "triggers.microscope"
      state: true
      timing: 60000              # "saturation done" marker
```

### 3. TRIALS (one phase per condition — see patterns below)

### 4. OLFACTOMETER DESATURATION (always 65 000 ms)
```yaml
- phase: "OLFACTOMETER DESATURATION"
  duration: 65000
  repeat: 0
  actions:
    - device: "olfactometer.left"
      state: "AIR"
      timing: 0
    - device: "olfactometer.right"
      state: "AIR"
      timing: 5
    - device: "switch_valve.left"
      state: "CLEAN"
      timing: 0
    - device: "switch_valve.right"
      state: "CLEAN"
      timing: 0
    - device: "triggers.microscope"
      state: true
      timing: 60000
```

### 5. SHUTDOWN SEQUENCE (always 2 000 ms)
```yaml
- phase: "SHUTDOWN SEQUENCE"
  duration: 2000
  repeat: 0
  actions:
    - device: "triggers.camera_continuous"
      state: false
      timing: 0
    - device: "olfactometer.left"
      state: "OFF"
      timing: 0
    - device: "olfactometer.right"
      state: "OFF"
      timing: 5
    - device: "switch_valve.left"
      state: "CLEAN"
      timing: 10
    - device: "switch_valve.right"
      state: "CLEAN"
      timing: 15
    - device: "mfc.air_left_setpoint"
      value: 0.0
      timing: 0
    - device: "mfc.air_right_setpoint"
      value: 0.0
      timing: 0
    - device: "mfc.odor_left_setpoint"
      value: 0.0
      timing: 0
    - device: "mfc.odor_right_setpoint"
      value: 0.0
      timing: 0
```

---

## Trial Phase Patterns

### Simple single-side pulse (N seconds on, then ISI)
```yaml
- phase: "TRIAL - LEFT ONLY"
  duration: 70000                # odor_duration + ISI_duration in ms
  repeat: 0
  actions:
    - device: "triggers.microscope"
      state: true
      timing: 0                  # trial start marker
    - device: "switch_valve.right"
      state: "CLEAN"             # explicit: unused side stays clean
      timing: 0
    - device: "switch_valve.left"
      state: "ODOR"
      timing: 0
    - device: "switch_valve.left"
      state: "CLEAN"
      timing: 30000              # odor off after 30 s
    - device: "triggers.microscope"
      state: true
      timing: 30000              # trial end marker
    # ISI: 40 s of silence → total duration = 70 000 ms
```

### Multi-pulse pattern (M pulses × P ms on / P ms off)
```yaml
# Example: 3 × 5 s on / 5 s off
- phase: "TRIAL - BILATERAL 3-PULSE"
  duration: 65000                # 25 s pulses + 40 s ISI
  repeat: 0
  actions:
    - device: "triggers.microscope"
      state: true
      timing: 0
    - device: "switch_valve.left"
      state: "ODOR"
      timing: 0
    - device: "switch_valve.right"
      state: "ODOR"
      timing: 0
    - device: "switch_valve.left"
      state: "CLEAN"
      timing: 5000
    - device: "switch_valve.right"
      state: "CLEAN"
      timing: 5000
    - device: "switch_valve.left"
      state: "ODOR"
      timing: 10000
    - device: "switch_valve.right"
      state: "ODOR"
      timing: 10000
    - device: "switch_valve.left"
      state: "CLEAN"
      timing: 15000
    - device: "switch_valve.right"
      state: "CLEAN"
      timing: 15000
    - device: "switch_valve.left"
      state: "ODOR"
      timing: 20000
    - device: "switch_valve.right"
      state: "ODOR"
      timing: 20000
    - device: "switch_valve.left"
      state: "CLEAN"
      timing: 25000
    - device: "switch_valve.right"
      state: "CLEAN"
      timing: 25000
    - device: "triggers.microscope"
      state: true
      timing: 25000
```

### Overlap trial (sequential with offset)
```yaml
# Left starts at t=0, right follows at t=OFFSET_ms.
# Overlap window = OFFSET_ms to left_end_ms.
# OFFSET must be ≥ 3 ms for guardrail safety.
- phase: "TRIAL - LEFT THEN RIGHT"
  duration: 70000
  repeat: 0
  actions:
    - device: "triggers.microscope"
      state: true
      timing: 0
    - device: "switch_valve.left"
      state: "ODOR"
      timing: 0
    - device: "switch_valve.right"
      state: "CLEAN"
      timing: 0                  # explicit no-odor until offset
    - device: "triggers.microscope"
      state: true
      timing: 10000              # right opens / overlap begins
    - device: "switch_valve.right"
      state: "ODOR"
      timing: 10000
    - device: "switch_valve.left"
      state: "CLEAN"
      timing: 30000
    - device: "switch_valve.right"
      state: "CLEAN"
      timing: 40000
    - device: "triggers.microscope"
      state: true
      timing: 40000
```

### Repeated trials (different odor each repeat)
```yaml
- phase: "ODOR IDENTITY TRIAL"
  duration: 90000
  times: 5                       # runs 5 times (replaces repeat: 4)
  randomize: true                # shuffle state list across repeats
  actions:
    - device: "olfactometer.left"
      state: "ODOR1,ODOR2,ODOR3,ODOR4,ODOR5"   # one per repeat
      timing: 0
    - device: "switch_valve.left"
      state: "ODOR"
      timing: 30000
    - device: "switch_valve.left"
      state: "CLEAN"
      timing: 60000
```

---

## Device Rules Cheat Sheet

| Rule | Detail |
|---|---|
| Simultaneous left+right writes | Offset by ≥ 5 ms: left at `T`, right at `T+5` |
| Minimum event spacing (same side) | ≥ 3 ms between any two timings on the same valve |
| MFC setpoint range | 0.0 – 5.0 V; typical odor flow = 0.03 V |
| Camera continuous | Start once in BOOT, stop once in SHUTDOWN |
| Microscope triggers | Use at trial start and end for alignment |
| Switch valves idle state | Always `CLEAN` between trials and in non-trial phases |
| Olfactometers idle state | `AIR` during saturation/desaturation, `OFF` only in SHUTDOWN |

---

## Timing Calculation Guide

Given `pulse_duration_s` and `ISI_s`:
```
phase_duration_ms = (pulse_duration_s + ISI_s) × 1000
```

For N pulses of P ms on / P ms off:
```
active_window_ms = N × (P_on + P_off) - P_off   # last off is ISI
                 = N × P_on + (N-1) × P_off
ISI_ms           = ISI_s × 1000
phase_duration_ms = active_window_ms + ISI_ms
```

For overlap trials with OFFSET_ms between sides:
```
total_active_ms  = single_side_window_ms + OFFSET_ms
overlap_window_ms = single_side_window_ms - OFFSET_ms   # (must be > 0)
phase_duration_ms = total_active_ms + ISI_ms
```

---

## Validation Checklist Before Running

- [ ] All `timing:` values are integers (no decimals)
- [ ] No two events on the same side differ by < 3 ms
- [ ] Left and right simultaneous-looking events are offset ≥ 5 ms
- [ ] Every trial phase starts with a `triggers.microscope` at `timing: 0`
- [ ] Every trial phase ends with a `triggers.microscope` at `timing: <odor_end>`
- [ ] Switch valves are explicitly set to `CLEAN` for unused side in unilateral trials
- [ ] `duration:` is always greater than the largest `timing:` value in that phase
- [ ] Olfactometers are set to odor in SATURATION (before trials)
- [ ] SHUTDOWN zeros all MFC `value:` to `0.0`
- [ ] Dry-run passes without errors: `python -m multibios.run_protocol --yaml config/<file>.yaml --hardware config/hardware.yaml --dry-run`

---

## YAML Anchors (Best Practice)

Define the active odor and flow once at the top and reference everywhere:
```yaml
_active_odor: &odor "ODOR2"        # change here → updates all phases
_mfc_flow: &mfc_flow 0.03

# Then use:
state: *odor
value: *mfc_flow
```

---

## Naming Conventions

- File names: `snake_case.yaml` (e.g. `odor_concentration_ramp.yaml`)
- Phase names: `"TRIAL N - CONDITION NAME"` (all caps, descriptive)
- Use comment blocks `# ──────────` to separate phases visually
- Include a header comment block with protocol purpose and odor anchor instructions

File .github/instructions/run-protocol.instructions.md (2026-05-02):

---
applyTo: "**"
---

# Running MultiBiOS Protocols

## Quick Reference

| Goal | Command |
|---|---|
| Dry-run (no hardware, generate preview) | `python -m multibios.run_protocol --yaml config/<file>.yaml --hardware config/hardware.yaml --dry-run --interactive` |
| Execute on hardware | `python -m multibios.run_protocol --yaml config/<file>.yaml --hardware config/hardware.yaml --verbose --progress` |
| Validate YAML only | `python -m multibios.run_protocol --yaml config/<file>.yaml --hardware config/hardware.yaml --dry-run` |
| Reproducible run with fixed seed | add `--seed 42` |
| Override timing params | add `--preload-lead-ms 3 --load-req-ms 1 --rck-ms 1 --trig-ms 5` |

All commands should be run from `c:\Rishika\MultiBiOS\`.

---

## Full CLI Reference

```
python -m multibios.run_protocol [OPTIONS]

Required:
  --yaml PATH           Protocol YAML file (default: protocols/example_protocol.yaml)
  --hardware PATH       Hardware mapping YAML (default: config/hardware.yaml)

Execution mode:
  --dry-run             Compile + validate only, no hardware output
  --interactive         Always save HTML preview (implied by --dry-run)

Output:
  --out-root PATH       Output directory root (default: data/runs)
  --verbose / -v        INFO-level logging
  --debug               DEBUG-level logging (very detailed, impacts timing)

Progress monitoring:
  --progress            Print real-time progress bar during execution
  --progress-interval N Update every N ms (default: 100)

Timing overrides (override values in YAML):
  --preload-lead-ms N   S-bit lead time before LOAD_REQ (default: 2)
  --load-req-ms N       LOAD_REQ pulse width (default: 1)
  --rck-ms N            RCK pulse width (default: 1)
  --trig-ms N           Trigger pulse width (default: 5)

Reproducibility:
  --seed N              Override protocol's RNG seed for randomization

Hardware:
  --device NAME         Override NI-DAQ device name (e.g. Dev2)
```

---

## Step-by-Step: First Run

### 1. Activate the correct environment
```powershell
conda activate base           # or your project env
cd C:\Rishika\MultiBiOS
```

### 2. Dry-run to validate and preview
```powershell
python -m multibios.run_protocol `
  --yaml protocols/odor_lateralization.yaml `
  --hardware config/hardware.yaml `
  --dry-run --interactive
```
This creates a timestamped folder under `data/runs/` containing `preview.html` — open it in any browser to inspect the waveform.

### 3. Check the compile report
The folder also contains `compile_report.json` and `digital_edges.csv`. Verify:
- All expected phases are listed
- Microscope trigger times match your intended trial markers
- No "guardrail violation" errors in the log

### 4. Execute on hardware
```powershell
python -m multibios.run_protocol `
  --yaml protocols/odor_lateralization.yaml `
  --hardware config/hardware.yaml `
  --verbose --progress
```
Progress output format: `[  5%] 250.0ms | DO:░█░░█ | AO:0:2.50,1:1.20`

---

## Checking a Run's Output

Output directory structure (`data/runs/YYYY-MM-DD_HH-MM-SS/`):
```
compiled_do.npz    ← digital output (play this to hardware)
compiled_ao.npz    ← analog output
capture_ai.npz     ← MFC flow readings (hardware run only)
compile_report.json
digital_edges.csv  ← every rising/falling edge with timestamp
rck_edges.csv      ← register-clock commit times
preview.html       ← interactive waveform viewer ← OPEN THIS FIRST
protocol.yaml      ← copy of input protocol
hardware.yaml      ← copy of hardware mapping
meta.json          ← device, duration, args
```

---

## Common Errors & Fixes

| Error | Likely Cause | Fix |
|---|---|---|
| `GuardrailViolation` | Two events on same assembly overlap within preload window | Space events ≥ 3 ms apart, or reduce `preload_lead_ms` |
| `KeyError: 'device.key'` | Device key not in hardware.yaml | Check spelling against hardware.yaml |
| `DAQmxError -200220` | NI-DAQ device not connected | Check USB, confirm device name with NI MAX |
| `ValueError: state list length mismatch` | State CSV has wrong count vs. `times:` | Match CSV length to phase repeat count |
| `FileNotFoundError` on YAML | Wrong path | Run from `MultiBiOS/` directory |
| `ModuleNotFoundError: multibios` | Wrong environment / not installed | `pip install -e .` in the MultiBiOS directory |

---

## Visualizing After a Run
```powershell
# Open the auto-generated preview
Start-Process "data/runs/<timestamp>/preview.html"

# Or regenerate visualization from saved data
python -m multibios.viz_protocol data/runs/<timestamp>/
```

---

## Running Tests (No Hardware Needed)
```powershell
# Quick functional validation
python tools/manual_checks/simple_test.py

# Full test suite
python -m pytest tests/
```

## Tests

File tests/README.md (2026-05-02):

# Automated Tests

This directory is now reserved for automated tests that are intended to run under `pytest`.

Current automated coverage includes:

- FicTrac client parsing, buffering, and callback integration
- FicTrac timing and parity audit helpers
- Teensy transcript handling
- trigger-path utility coverage that can run without moving the live operator scripts back into the pytest tree

Run the focused automated suite from the repo root with:

```bash
pytest tests/
```

For a narrower slice:

```bash
pytest tests/test_fictrac_client.py tests/test_experiment_fictrac_callback.py
```

Operator-facing hardware checks and ad hoc bench utilities have been moved to [tools/manual_checks](../tools/manual_checks). Use that directory, or the PowerShell wrappers in [tools](../tools), for live camera, FicTrac, DAQ, and MFC validation.

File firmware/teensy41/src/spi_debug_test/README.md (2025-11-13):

# SPI Debug Test Firmware

This firmware provides systematic testing of the SPI output chain for MultiBiOS hardware debugging.

## Purpose

The original firmware relies on interrupt-driven responses to DAQ signals. This debug version eliminates all complex logic and generates predictable, repeating SPI patterns that you can easily verify with an oscilloscope.

## Features

- **6 Different Test Modes** with distinct, recognizable patterns
- **Adjustable SPI Clock Speed** (100 kHz to 10 MHz)
- **Serial Monitor Control** for interactive testing
- **Visual LED Feedback** during transmissions
- **Detailed Pattern Logging** to serial monitor

## Test Modes

### 1. ALL ZEROS (Mode 0)
- **Pattern**: `0x0000 0x0000 0x00 0x00`
- **Scope View**: MOSI should stay LOW throughout transmission
- **Use**: Verify SPI clock is working, check for stuck-high lines

### 2. ALL ONES (Mode 1)  
- **Pattern**: `0xFFFF 0xFFFF 0xFF 0xFF`
- **Scope View**: MOSI should stay HIGH throughout transmission
- **Use**: Verify SPI can drive high, check for stuck-low lines

### 3. ALTERNATING BITS (Mode 2)
- **Pattern A**: `0x5555 0xAAAA 0x55 0xAA`
- **Pattern B**: `0xAAAA 0x5555 0xAA 0x55`
- **Scope View**: Regular HIGH/LOW pattern on MOSI
- **Use**: Check for bit timing issues, verify data integrity

### 4. WALKING ONES (Mode 3)
- **Pattern**: Single '1' bit walks through all 48 positions
- **Scope View**: Single high pulse walks through the 48-bit frame
- **Use**: Verify all bit positions reach the output, check shift register operation

### 5. COUNTING (Mode 4)
- **Pattern**: Incrementing counter in each field
- **Scope View**: Increasing complexity of bit patterns
- **Use**: Test dynamic patterns, verify no bit positions are stuck

### 6. CUSTOM PATTERNS (Mode 5)
- **Pattern 1**: `0x1234 0x5678 0x9A 0xBC` (unique nibbles)
- **Pattern 2**: `0x0001 0x0002 0x04 0x08` (powers of 2)
- **Pattern 3**: `0x0003 0x000C 0x03 0x00` (air valve simulation)
- **Pattern 4**: `0x0FFF 0x0FFF 0xFF 0xFF` (flush state simulation)

## Hardware Setup

### Oscilloscope Connections
1. **Channel 1**: Connect to Pin 11 (MOSI) - Data signal
2. **Channel 2**: Connect to Pin 13 (SCK) - Clock signal  
3. **Ground**: Connect scope ground to Teensy ground

### Oscilloscope Settings
- **Timebase**: Start with 10µs/div (adjust based on SPI speed)
- **Trigger**: Channel 2 (SCK) rising edge
- **Voltage**: 5V/div for both channels
- **Coupling**: DC

## Expected Waveforms

### SPI Frame Structure
```
[16-bit OLFA_L][16-bit OLFA_R][8-bit SW_L][8-bit SW_R] = 48 total bits
```

### Timing at 1 MHz SPI Clock
- **Bit period**: 1µs per bit
- **Frame duration**: 48µs per complete frame
- **Frame interval**: 500ms between frames (configurable)

## Usage Instructions

### 1. Upload Firmware
```bash
# In Arduino IDE or PlatformIO
# Select: Teensy 4.1, USB Type: Serial
# Upload spi_debug_test.ino
```

### 2. Open Serial Monitor
```bash
# Baud rate: 115200
# Watch for startup messages and pattern descriptions
```

### 3. Interactive Commands
- **`n`**: Switch to next test mode
- **`s`**: Show SPI speed options
- **`1-4`**: Set SPI speed (100kHz, 1MHz, 5MHz, 10MHz)
- **`r`**: Reset pattern counter

### 4. Oscilloscope Analysis

#### What to Look For:
1. **Clock Signal (SCK)**: Should be clean square wave at set frequency
2. **Data Signal (MOSI)**: Should change on clock edges
3. **Frame Timing**: 48 clock cycles per frame, then 500ms gap
4. **Pattern Recognition**: Verify the transmitted pattern matches expected

#### Troubleshooting Guide:

**No Clock Signal (SCK)**
- Check Pin 13 connection
- Verify SPI initialization in serial monitor
- Try different SPI speeds

**No Data Signal (MOSI)**  
- Check Pin 11 connection
- Verify SPI is sending data (LED should blink)
- Check for loose connections

**Incorrect Data Patterns**
- Use ALL ZEROS/ALL ONES modes first
- Check for bit timing issues with ALTERNATING mode
- Use WALKING ONES to verify all bit positions

**Downstream Circuit Issues**
- Connect scope to shift register inputs
- Verify power supply to downstream ICs
- Check for proper grounding

## Example Serial Output

```
=== MultiBiOS SPI Debug Test ===
Version 1.0

SPI initialized at 1000000 Hz
Testing SPI connection...

========================================
SWITCHED TO MODE: ALL ZEROS
Scope: Look for constant LOW on MOSI
========================================

Pattern: ALL ZEROS - 0x0000 0x0000 0x00 0x00
Pattern: ALL ZEROS - 0x0000 0x0000 0x00 0x00
...
```

## Advanced Debugging

### Custom Pattern Testing
Modify the `generateCustomPatterns()` function to test specific valve combinations that aren't working in your main firmware.

### Speed Optimization
Start testing at 100 kHz (easy to see on scope), then increase speed to find the maximum reliable rate for your circuit.

### Continuous vs. Burst Mode
Current firmware sends frames every 500ms. Modify the delay to test continuous transmission or burst patterns.

## Comparison with Main Firmware

| Feature | Debug Firmware | Main Firmware |
|---|---|---|
| **Trigger** | Continuous/Timed | Interrupt-driven |
| **Patterns** | Predictable test patterns | Dynamic based on DAQ inputs |
| **Timing** | 500ms intervals | Microsecond response |
| **Complexity** | Simple loops | ISRs + state management |
| **Debug** | Extensive logging | Limited logging |

Use this debug firmware to verify the SPI output chain works correctly, then return to the main firmware once hardware issues are resolved.

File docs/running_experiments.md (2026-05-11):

# Running a New Experiment

This guide walks you through everything needed to design, validate, and execute an olfactometer experiment with MultiBiOS — from first boot to data saved on disk.

---

## Before You Start — Hardware Checklist

Complete this checklist each session before launching any software:

- [ ] **NI USB-6353** connected via USB; visible in NI MAX as `Dev1`
- [ ] **Teensy 4.1** connected via USB; firmware uploaded (see [`docs/firmware.md`](firmware.md))
- [ ] **Shift-register chains** (TPIC6B595) wired to Teensy SPI (MOSI=Pin 11, SCK=Pin 13)
- [ ] **Olfactometer valve arrays** powered (12 V solenoids) and connected to shift-register outputs
- [ ] **MFCs** powered; setpoint cables to DAQ `ao0–ao3`; feedback cables to DAQ `ai0–ai3`
- [ ] **Gas lines** connected: air and odor carrier gas flows to left/right olfactometer inlets
- [ ] Windows Device Manager — confirm Teensy COM port is assigned and no yellow warning icons
- [ ] NI MAX — confirm device name is `Dev1` (if different, update `config/hardware.yaml`)

> **Tip:** If this is the first session on this PC, follow the one-time [Software Setup](#software-setup-first-time-only) section below first.

---

## Software Setup (First Time Only)

```powershell
# 1. Create the shared MultiBiOS + Blackfly camera environment:
cd C:\Rishika\MultiBiOS
conda env create -f environment.yml
conda activate multibios-blackfly

# 2. Verify the DAQ + camera stack:
python -c "import multibios, nidaqmx, PySpin; print('multibios-blackfly ready')"

# 3. Verify the protocol runner:
python -m multibios.run_protocol --help
```

Use the shared Conda environment named `multibios-blackfly` so the DAQ control code and the Teledyne FLIR Blackfly S cameras run in the same Python installation.

Rig camera model for this setup:

- Front camera: **Blackfly S BFS-U3-13Y3M**
- Side/FicTrac camera: **Blackfly S BFS-U3-13Y3M**

If you want to use the side camera with live FicTrac on this rig, build and use the Spinnaker-enabled binary documented in [`docs/fictrac.md`](fictrac.md). The validated packaged path on this workstation is `C:/Rishika/MultiBiOS/assets/fictrac-spinnaker/fictrac-spinnaker.exe`.

NI-DAQmx drivers must be installed separately from
[ni.com/downloads](https://www.ni.com/en/support/downloads/drivers/download.ni-daq-mx.html), and the matching Spinnaker SDK must be installed before the bundled `PySpin` wheel.

---

## Choose the Runner

Use the supported execution path below.

| Runner | When to use it | Timing model | FicTrac | Typical outputs |
| --- | --- | --- | --- | --- |
| `python -m multibios.run_protocol` | Default path for all new experiments | Hardware-clocked NI-DAQ waveform | Supported when `hardware.yaml -> fictrac` is configured | `compiled_do.npz`, `capture_ai.npz`, optional `fictrac_frames.npz` |

!!! warning "Legacy serial runner"
  `multibios.experiment` is deprecated. Its operational notes have moved to [legacy/serial_experiment_pipeline.md](legacy/serial_experiment_pipeline.md) and are intentionally hidden from the default docs navigation.

---

## Step 1 — Choose or Create a Protocol

Protocol files live in `config/`. Existing protocols:

| File | What it tests |
| --- | --- |
| `odor_lateralization.yaml` | 5 conditions: bilateral, left-only, right-only, left→right overlap, right→left overlap. Single 30 s pulses. |
| `odor_lateralization_3pulse.yaml` | Same 5 conditions with 3 × 5 s pulses instead. |
| `example_protocol.yaml` | Full-featured reference with randomized odor delivery. |
| `short_protocol.yaml` | Abbreviated 9 s trials — good for hardware sanity checks. |
| `switch_valve_test.yaml` | Switch valve toggling only — no odor. |

**To use an existing protocol**, skip to [Step 2](#step-2--set-the-odor).

**To create a new protocol**, open a copy of the closest existing YAML and edit it.
See [`docs/protocol.md`](protocol.md) for the full YAML schema, or ask Copilot — the design
instructions at `.github/instructions/design-protocol.instructions.md` provide a full
template and all device rules.

---

## Step 2 — Set the Odor

Every `odor_lateralization*.yaml` file has a single anchor at the top:

```yaml
_active_odor: &odor "ODOR1"       # ← change this line only
_mfc_odor_flow_slpm: &mfc_flow 0.03
```

Change `"ODOR1"` to whichever odor channel is loaded today (`ODOR1`–`ODOR5`).
This propagates automatically to every phase — you do **not** need to edit individual actions.

Valid odor values: `ODOR1`  `ODOR2`  `ODOR3`  `ODOR4`  `ODOR5`  `FLUSH`

---

## Step 3 — Dry Run (Validate Without Hardware)

Always validate the protocol before touching real hardware:

```powershell
cd C:\Rishika\MultiBiOS

conda run -n multibios-blackfly python -m multibios.run_protocol `
  --yaml protocols/odor_lateralization.yaml `
  --hardware config/hardware.yaml `
  --dry-run --interactive
```

This compiles the protocol and writes a preview to a new timestamped folder:

```text
data/runs/YYYY-MM-DD_HH-MM-SS/
  preview.html        ← open this in your browser
  digital_edges.csv   ← every valve transition with timestamps
  compile_report.json ← timing log and guardrail summary
```

**Open `preview.html`** in Chrome or Edge and verify:

- Odor pulses appear at the right times on the right valves
- Microscope trigger markers align with trial start/end
- Camera trigger runs continuously throughout
- MFC setpoints ramp to the expected flow voltage at boot and drop to 0 at shutdown
- No overlapping events on the same valve

If the compiler finds a timing violation it will print a `GuardrailViolation` error and
stop. Fix the offending timing offset in the YAML (space events ≥ 3 ms apart on the same
side) and re-run the dry run.

---

## Step 4 — Connect the Animal and Begin Imaging

1. Mount the animal and confirm head fixation.
2. Start your imaging/recording software (two-photon, widefield, electrophysiology, etc.)
   and set it to **wait for an external trigger** on the microscope trigger line.
3. Leave the imaging software armed — MultiBiOS will send the first microscope pulse at the
   end of the saturation phase to mark "trials starting".

Before a long real experiment, run one bounded hardware sanity check on the rig:

```powershell
cd C:\Rishika\MultiBiOS

conda run -n multibios-blackfly python -m multibios.run_protocol `
  --yaml protocols/short_protocol.yaml `
  --hardware config/hardware.yaml `
  --verbose --progress
```

That validated command finishes on its own in a few seconds and confirms the current DAQ/FicTrac/camera stack on this workstation.

---

## Step 5 — Run the Experiment

```powershell
cd C:\Rishika\MultiBiOS

conda run -n multibios-blackfly python -m multibios.run_protocol `
  --yaml protocols/odor_lateralization.yaml `
  --hardware config/hardware.yaml `
  --verbose --progress
```

If you want the native live FicTrac display window during a long interactive run, add `--fictrac-display`. MultiBiOS otherwise forces long high-rate runs into headless mode once they exceed the validated automation threshold.

If `config/hardware.yaml` contains a `fictrac:` block, `run_protocol` now also:

- prepares the Spinnaker runtime path for the child process
- launches FicTrac automatically
- waits for the first UDP frame using `fictrac.startup_timeout_s`
- writes run-local FicTrac artifacts into the same `data/runs/<timestamp>/` folder

The canonical config uses `fictrac.first_frame_timeout_ms: 0`, so the native FicTrac layer waits indefinitely for the first frame by default. Set `fictrac.startup_timeout_s: 0` as well when you want the Python runner to wait indefinitely for the first UDP frame.

The terminal prints a real-time progress bar:

```text
[  5%]  3250.0ms | DO:░█░░░ | AO:0:0.03,1:0.03,2:0.03,3:0.03
[ 12%]  9100.0ms | DO:█░░░█ | AO:0:0.03,1:0.03,2:0.03,3:0.03
...
[100%] Protocol execution complete
```

**Do not close the terminal or disconnect hardware while the bar is running.**

The protocol ends automatically. All output is saved immediately to
`data/runs/<timestamp>/`.

---

## Step 6 — Verify the Data

After the run, open `data/runs/<timestamp>/capture_ai.npz` (MFC feedback) and
`digital_edges.csv` to confirm the hardware responded correctly:

```powershell
# Quick check — view edge timestamps
Get-Content data/runs/<timestamp>/digital_edges.csv | Select-Object -First 30
```

Or re-open the `preview.html` from this run — for hardware runs it will include
the actual AI (MFC feedback) traces overlaid on the planned waveform.

---

## Step 7 — Re-run with the Same Randomization (Optional)

If your protocol uses randomized odor orders, the seed is saved in `meta.json`.
To reproduce an identical run:

```powershell
conda run -n multibios-blackfly python -m multibios.run_protocol `
  --yaml config/my_protocol.yaml `
  --hardware config/hardware.yaml `
  --seed <seed_from_meta.json>
```

---

## Output File Reference

Every run creates `data/runs/YYYY-MM-DD_HH-MM-SS/`:

| File | Description |
| --- | --- |
| `preview.html` | Interactive Plotly waveform viewer |
| `compiled_do.npz` | Digital output array — shape `(num_lines, samples)` |
| `compiled_ao.npz` | Analog output array — shape `(num_ao, samples)` |
| `capture_ai.npz` | MFC flow feedback recorded during the run |
| `digital_edges.csv` | Every rising/falling edge with ms timestamp |
| `rck_edges.csv` | Register-clock commit times |
| `compile_report.json` | Phases, guardrail log, RCK edge count |
| `meta.json` | Device name, sample rate, seed, CLI args used |
| `protocol.yaml` | Exact copy of the protocol that was run |
| `hardware.yaml` | Exact copy of the hardware config used |

When FicTrac is enabled for `run_protocol`, the same run directory also includes:

| File | Description |
| --- | --- |
| `fictrac_runtime_config.txt` | The exact runtime config passed to FicTrac |
| `fictrac_runtime.json` | MultiBiOS-side summary of the runtime config edits |
| `fictrac_driver_diagnostics.json` | Launch diagnostics including first-packet timing and frame count |
| `fictrac_frames.npz` | Saved FicTrac frames from the internal client |
| `fictrac-*.dat` | Native FicTrac output |

---

## Common Problems

| Symptom | Likely Cause | Fix |
| --- | --- | --- |
| `GuardrailViolation` on compile | Two events on the same valve < 3 ms apart | Increase spacing between `timing:` values |
| `DAQmxError -200220` | NI-DAQ not found | Check USB, confirm device name in NI MAX matches `hardware.yaml` |
| `ModuleNotFoundError: multibios` | Wrong environment | Activate or use `multibios-blackfly`, then run `conda run -n multibios-blackfly ...` |
| `FicTrac did not produce any frames within N s` | FicTrac camera config or startup wait mismatch | Check `hardware.yaml -> fictrac`, verify `fictrac-spinnaker.exe`, and use `first_frame_timeout_ms: 0` plus `startup_timeout_s: 0` when you want indefinite startup wait |
| Valves don't respond | Teensy not ready | Check Teensy USB, confirm firmware; watch for READY signal in `di_edges.csv` |
| MFC feedback all zeros | AI wiring or ground issue | Check MFC feedback cables to `ai0–ai3` and common ground |
| Progress bar never starts | DAQ task not starting | Check hardware connection; try `--debug` for detailed log |
| Wrong odor delivered | YAML anchor not updated | Make sure you changed `_active_odor: &odor "ODORx"` at the top of the YAML |

For more diagnostics see [`docs/troubleshooting.md`](troubleshooting.md).

---

## Quick Reference — Common Commands

```powershell
# Validate a protocol (no hardware needed)
conda run -n multibios-blackfly python -m multibios.run_protocol --yaml config/<file>.yaml --hardware config/hardware.yaml --dry-run --interactive

# Run on hardware with live progress
conda run -n multibios-blackfly python -m multibios.run_protocol --yaml config/<file>.yaml --hardware config/hardware.yaml --verbose --progress

# Run with a fixed random seed
conda run -n multibios-blackfly python -m multibios.run_protocol --yaml config/<file>.yaml --hardware config/hardware.yaml --seed 42

# Regenerate visualization from saved data
conda run -n multibios-blackfly python -m multibios.viz_protocol data/runs/<timestamp>/

# Run hardware sanity check (short protocol, no animal needed)
conda run -n multibios-blackfly python -m multibios.run_protocol --yaml protocols/short_protocol.yaml --hardware config/hardware.yaml --verbose --progress

```

All commands should be run from `C:\Rishika\MultiBiOS\`.
If you still need the deprecated serial/Alicat `experiment.py` workflow, its commands, config notes, and troubleshooting now live in [legacy/serial_experiment_pipeline.md](legacy/serial_experiment_pipeline.md).

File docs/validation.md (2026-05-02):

# Validation & QA

## Functional tests (no valves)

1. **Preview compile**  
   `python -m multibios.run_protocol --yaml protocols/example_protocol.yaml --hardware config/hardware.yaml --dry-run --interactive --seed 1`
   - Inspect `preview.html`. Confirm state rails read sensibly; RCK markers align to commits.

2. **Guardrail test**  
   Create two actions with commits closer than `preload_lead_ms + max(load_req_ms,rck_pulse_ms)` and confirm the compiler raises a helpful error.

3. **Randomization reproducibility**  
   Run twice with the same `--seed` and confirm:
   - Identical `digital_edges.csv`
   - Identical `preview.html` (modulo timestamps in `meta.json`)

## Hardware tests (with MFC loopback or live MFCs)

### Protocol parity checks

Use the dedicated tool entry points when you want an end-to-end frame-count parity check across:

- trigger rising edges
- FicTrac raw saved frames
- FicTrac UDP frame count
- FicTrac callback frame count
- second-camera saved frames

Short-run smoke test:

```powershell
.\tools\run_short_frame_parity_test.ps1 -VerboseOutput -Progress
```

Long-run parity test:

```powershell
.\tools\run_long_frame_parity_test.ps1 -VerboseOutput -Progress
```

Behavior:

- both scripts run `multibios.run_protocol`
- both then run `multibios.parity_audit` on the newly created run directory
- nonzero exit means either the protocol run itself failed or trigger/frame parity failed
- the detailed audit is written to `parity_audit.json` inside the run directory

Defaults:

- short-run test uses `protocols/short_protocol.yaml`
- long-run test uses `protocols/odor_lateralization.yaml`
- both use `config/hardware.yaml` unless you override `-HardwarePath`

Optional debugging aid:

- pass `-KeepRawChunks` if you want the parity test to temporarily force `raw_chunk_retention_policy: keep` for that run so the raw `.bin` chunks remain available for manual inspection even when the main hardware config is set to `delete_after_parity`

1. **MFC AO/AI tracking** — see [MFC Analog Test](mfc_analog_test.md) for the full reference.

   Quick pre-session sweep (all four channels, ±0.1 V tolerance):

   ```bash
   python tools/manual_checks/mfc_analog_test.py sweep
   ```

   Live monitor while setting setpoints manually:

   ```bash
   python tools/manual_checks/mfc_analog_test.py monitor --set air_left=2.5 odor_right=1.0
   ```

   Exit code 0 = PASS.  Exit code 1 = one or more channels outside tolerance — investigate before running an experiment.

2. **Latency sanity**
   - Use the viewer’s vertical rulers and hover readouts to confirm spacing between S-bit switch, LOAD_REQ, and RCK matches YAML timing.

3. **Valve drive sanity (dry run)**  
   - Disconnect 24 V loads; probe RCK & S-lines for clean edges and no ringing.

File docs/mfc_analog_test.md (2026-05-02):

# MFC Analog Test Interface

`tools/manual_checks/mfc_analog_test.py` is the primary tool for verifying and monitoring
the four mass-flow controller (MFC) channels.  It replaces the legacy
serial-based `flow_monitor` and talks directly to the NI-DAQ board — the same
hardware path used during live experiments.

## Background: how MFC control works

MFCs are controlled **entirely over analog voltage** via the NI USB-6353:

| Signal | Direction | Channels | Voltage |
|---|---|---|---|
| Setpoint | DAQ → MFC | `Dev1/ao0-3` | 0–5 V (maps to 0–100 % full scale) |
| Feedback | MFC → DAQ | `Dev1/ai0-3` | 0–5 V (actual flow readback) |

The channel names (`mfc.air_left_setpoint`, etc.) are defined in
[config/hardware.yaml](../config/hardware.yaml).  The test script reads that
file directly, so it stays in sync automatically if pin assignments change.

!!! note "Serial control removed"
    The previous `AlicatManager` / `flow_monitor` serial path has been moved
    to `legacy/`.  Do not use it for new work — serial ports are no longer
    wired to the MFCs.

---

## Modes

### `monitor` — live setpoint + feedback display

Applies initial setpoints, then continuously reads AI feedback and prints a
live table at the configured interval.  All setpoints are zeroed automatically
on `Ctrl+C` (pass `--no-zero-on-exit` to suppress).

```bash
# Watch current flow with all channels at 0 V
python tools/manual_checks/mfc_analog_test.py monitor

# Apply setpoints before monitoring
python tools/manual_checks/mfc_analog_test.py monitor --set air_left=2.5 odor_right=1.0

# Faster poll, no auto-zero on exit
python tools/manual_checks/mfc_analog_test.py monitor --interval 0.2 --no-zero-on-exit
```

**Display columns:**

| Column | Meaning |
|---|---|
| `Setpt (V)` | Commanded AO voltage |
| `Feedback (V)` | Mean of 20 AI samples |
| `Flow (% FS)` | `feedback / 5.0 × 100 %` (full-scale percentage) |
| `Δ (V)` | `feedback − setpoint` |
| `✓ / ⚠` | Green tick if `\|Δ\| ≤ 0.15 V`, warning otherwise |

---

### `sweep` — linearity / pass-fail test

Steps each AO channel through a list of voltage levels (one channel at a time,
all others held at 0 V) and compares the AI readback against the commanded
value.  Returns **exit code 0** on full PASS, **exit code 1** if any channel
fails, making it usable in CI.

```bash
# Default sweep: 0 → 1 → 2 → 3 → 4 → 5 → 0 V, 0.5 s dwell, ±0.1 V tolerance
python tools/manual_checks/mfc_analog_test.py sweep

# Tighter tolerance, longer dwell
python tools/manual_checks/mfc_analog_test.py sweep --tolerance 0.05 --dwell 1.0

# Sweep a subset of channels only
python tools/manual_checks/mfc_analog_test.py sweep --channels air_left odor_left

# Custom voltage steps
python tools/manual_checks/mfc_analog_test.py sweep --levels 0 2.5 5 0
```

**Example output:**

```
Sweep: [0.0, 1.0, 2.0, 3.0, 4.0, 5.0, 0.0] V  dwell=0.50s  tol=0.100 V

  Channel: air_left
    ✓  set=0.00 V  read=0.0031 V  err=+0.0031 V
    ✓  set=1.00 V  read=0.9987 V  err=-0.0013 V
    ✓  set=2.00 V  read=1.9994 V  err=-0.0006 V
    ...

── Sweep Summary ──────────────────────────────
  [PASS] air_left         worst_error=0.0031 V  (tol=0.100 V)
  [PASS] air_right        worst_error=0.0028 V  (tol=0.100 V)
  [PASS] odor_left        worst_error=0.0041 V  (tol=0.100 V)
  [PASS] odor_right       worst_error=0.0019 V  (tol=0.100 V)

ALL PASS
```

---

## Dry-run mode

Prints the resolved channel map without touching hardware.  Use this to
confirm `hardware.yaml` is being parsed correctly before connecting devices.

```bash
python tools/manual_checks/mfc_analog_test.py --dry-run monitor
```

```
Hardware: C:\Rishika\MultiBiOS\config\hardware.yaml
MFC AO channels:
  air_left        AO -> Dev1/ao0  AI -> Dev1/ai0
  air_right       AO -> Dev1/ao1  AI -> Dev1/ai1
  odor_left       AO -> Dev1/ao2  AI -> Dev1/ai2
  odor_right      AO -> Dev1/ao3  AI -> Dev1/ai3

[dry-run] Hardware not touched.
```

---

## Custom hardware config

```bash
python tools/manual_checks/mfc_analog_test.py --hardware path/to/other_hardware.yaml sweep
```

The `--hardware` flag defaults to `config/hardware.yaml` relative to the
repository root.

---

## Channel names

| Logical name | AO channel | AI channel | MFC |
|---|---|---|---|
| `air_left` | `Dev1/ao0` | `Dev1/ai0` | Air — left side |
| `air_right` | `Dev1/ao1` | `Dev1/ai1` | Air — right side |
| `odor_left` | `Dev1/ao2` | `Dev1/ai2` | Odour — left side |
| `odor_right` | `Dev1/ao3` | `Dev1/ai3` | Odour — right side |

Voltages map to flow as:

$$
V_\text{setpoint} = \frac{\text{setpoint (sccm)}}{\text{full-scale (sccm)}} \times 5\,\text{V}
$$

$$
\text{flow (sccm)} = \frac{V_\text{feedback}}{5\,\text{V}} \times \text{full-scale (sccm)}
$$

The full-scale value depends on the MFC model ordered — check the label on
each device.

---

## Safety notes

- The AO range is **0–5 V**.  Values are clamped before writing; you cannot
  accidentally command a negative or over-range voltage through this tool.
- `monitor` mode **always zeros all channels on exit** unless `--no-zero-on-exit`
  is passed.  In `sweep` mode, channels are zeroed automatically at the end of
  the sweep regardless of outcome.
- Do not run this tool simultaneously with `run_protocol.py` — both write to
  the same AO channels.

---

## Integration with the pre-connect checklist

The `sweep` command is the programmatic equivalent of the manual steps in
[Pre-Connect Oscilloscope Checklist](preconnect_scope_checklist.md).  Run it
after bench-testing with a scope to confirm the full AO → MFC → AI loop closes
correctly before starting an experiment session.

```bash
# Recommended pre-session check
python tools/manual_checks/mfc_analog_test.py sweep --dwell 1.0
```

Exit code 0 = all channels within tolerance.  Exit code 1 = investigate before
proceeding.

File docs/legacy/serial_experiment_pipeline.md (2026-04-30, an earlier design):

# Legacy Serial Experiment Pipeline

`multibios.experiment` remains in the module for compatibility, but it is deprecated for new experiments.

Use [../running_experiments.md](../running_experiments.md) and [../runner.md](../runner.md) for the supported hardware-clocked `multibios.run_protocol` workflow.

## Status

- Deprecated runner: `python -m multibios.experiment`
- Timing model: computer-timed serial valve/MFC events plus a finite NI-DAQ trigger task
- Kept for: historical serial/Alicat workflows, old run replay, and transition-period rig support

## Command Reference

```powershell
cd C:\Rishika\MultiBiOS

conda run -n multibios-blackfly python -m multibios.experiment `
  --protocol protocols/odor_lateralization.yaml `
  --hardware config/hardware.yaml `
  --experiment config/experiment_config.yaml `
  --verbose
```

Short bounded probe:

```powershell
cd C:\Rishika\MultiBiOS

conda run -n multibios-blackfly python -m multibios.experiment `
  --protocol protocols/short_protocol.yaml `
  --hardware config/hardware.yaml `
  --experiment config/experiment_config_probe.yaml
```

Dry run preview:

```powershell
cd C:\Rishika\MultiBiOS

conda run -n multibios-blackfly python -m multibios.experiment `
  --protocol protocols/odor_lateralization.yaml `
  --hardware config/hardware.yaml `
  --experiment config/experiment_config.yaml `
  --dry-run --verbose
```

## Configuration

The deprecated runner still depends on both config files below.

### `config/hardware.yaml`

This remains the rig-level source of truth for DAQ and FicTrac settings:

```yaml
fictrac:
  config: "config_camera.txt"
  bin: "C:/Rishika/MultiBiOS/assets/fictrac-spinnaker/fictrac-spinnaker.exe"
  console_out: "fictrac_output.txt"
  first_frame_timeout_ms: 0
  startup_timeout_s: 90.0
  timeout_s: 5.0
```

### `config/experiment_config.yaml`

This file is legacy-runner-specific and contains the serial/Alicat settings:

```yaml
teensy_port: "COM4"
teensy_baud: 115200

mfc_mode: "alicat_serial"

mfc_device_map:
  mfc.air_left_setpoint:   "A"
  mfc.air_right_setpoint:  "B"
  mfc.odor_left_setpoint:  "C"
  mfc.odor_right_setpoint: "D"

alicat_ports: ["COM7", "COM8", "COM9", "COM10"]
alicat_baud: [115200]

latch_interval_ms: 10.0
mfc_live_interval_s: 1.0
data_dir: "data/runs"
```

## Runner Differences

| | `multibios.run_protocol` | `multibios.experiment` |
| --- | --- | --- |
| Valve control | Hardware-clocked NI-DAQ waveform | Computer-timed serial to Teensy |
| MFC control | DAQ analog output | Alicat serial |
| FicTrac | Integrated through `hardware.yaml -> fictrac` | Integrated through `hardware.yaml -> fictrac` |
| Camera/scope triggers | Embedded in DAQ waveform | Separate finite NI-DAQ task |
| Intended use | Supported default path | Deprecated compatibility path |

## FicTrac Notes

For the live Blackfly side camera, validate the rebuilt binary first using the probe flow in [../fictrac.md](../fictrac.md).

The deprecated runner still:

- prepares the Spinnaker runtime path
- starts the FicTrac thread and waits for the first frame
- records the experiment event stream alongside FicTrac output

Use `fictrac.first_frame_timeout_ms: 0` together with `fictrac.startup_timeout_s: 0` when you want both layers to wait indefinitely for the first externally triggered frame.

## Output Files

The legacy run directory contains files such as:

- `experiment_data.csv`
- `event_log.csv`
- `event_log.json`
- `timeline.csv`
- `trigger_waveform.npz`
- `fictrac_runtime_config.txt`
- `fictrac_driver_diagnostics.json`
- `fictrac-*.dat`
- `protocol.yaml`
- `hardware.yaml`
- `meta.json`

## Troubleshooting

| Symptom | Likely Cause | Fix |
| --- | --- | --- |
| `FicTrac did not produce any frames within N s` | Camera not found, FicTrac crashed, or the first-frame wait is too short | Check `hardware.yaml -> fictrac`, verify the packaged `fictrac-spinnaker.exe`, and increase `startup_timeout_s` or set it to `0` |
| `No cached Alicat device matches mapping` | Wrong letter ID or COM port | Run `python -m multibios.apps.flow_monitor --scan` and update `mfc_device_map` |
| `Teensy RESET: ERROR` | Wrong COM port or firmware not running | Check Device Manager for the correct port and re-flash firmware |
| High jitter on valve events | Host CPU load | Close non-essential applications and avoid using this path for timing-critical runs |

## CLI Reference

```text
conda run -n multibios-blackfly python -m multibios.experiment [OPTIONS]

Required:
  --protocol FILE       Protocol YAML
  --hardware FILE       Hardware mapping YAML
  --experiment FILE     Experiment config YAML (default: config/experiment_config.yaml)

Execution:
  --dry-run             Preview timeline only; no hardware
  --verbose / -v        Print each event with jitter as it fires
  --seed INT            Override protocol RNG seed

Output:
  --out-root DIR        Output root (default: from experiment_config.yaml data_dir)
```

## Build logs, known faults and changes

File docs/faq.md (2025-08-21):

# Frequently Asked Questions

## System Architecture

??? question "Why separate preload and commit?"
    The separation of preload and commit operations allows the DAQ to timestamp the commit with hardware precision and coordinate multiple valve assemblies independently. This ensures sub-millisecond timing accuracy even under system load.

??? question "What does the guardrail prevent?"
    The compile-time guardrail prevents overlapping "preload→commit" windows where two assemblies would both be staged simultaneously. The Teensy firmware is designed to handle exactly one staged owner at a time for safety and reliability.

??? question "Why use sticky S-bits?"
    Sticky S-bits make digital rails represent the **current logical state** between events, which simplifies verification and downstream analysis. This provides a clear representation of what the system is actually doing at any given moment.

## Timing and Performance

??? question "Can I use 0.1 ms timing resolution?"
    Yes! Set `sample_rate: 10000` in your protocol configuration and ensure your USB-6353 and host computer can handle the higher sample rate. All system components (guardrails, viewer, logging) automatically scale with the sample rate.

??? question "What's the maximum sample rate supported?"
    The system supports up to 10 kHz (0.1 ms resolution) with the NI USB-6353. Higher rates may be possible but haven't been extensively tested. The limiting factors are typically USB bandwidth and host system performance.

??? question "How precise is the timing really?"
    Hardware-clocked events have microsecond precision determined by the NI-DAQ clock. Software events (like protocol phase transitions) have millisecond precision. The sticky S-bit approach ensures valve states are always synchronized to the hardware clock.

## Hardware and Setup

??? question "Can I use a different DAQ device?"
    The system is designed around the NI USB-6353's capabilities, but could potentially be adapted to other NI-DAQ devices with sufficient digital I/O and analog channels. This would require modifications to the hardware configuration and possibly the runner code.

??? question "How many valve assemblies can I control?"
    The current firmware supports 4 shift register chains (olfactometer_left, olfactometer_right, switchvalve_left, switchvalve_right), each controlling 8 valves. This could be extended by modifying the firmware and hardware configuration.

??? question "What if I need more trigger outputs?"
    The current system provides microscope triggers and continuous camera triggers. Additional trigger types can be added by modifying the hardware mapping and protocol schema. The NI-DAQ has additional digital output channels available.

## Protocol Development

??? question "How do I test protocols without hardware?"
    Use the `--dry-run` flag with the runner. This generates all the timing data and visualizations without attempting to communicate with actual hardware. Perfect for protocol development and debugging.

??? question "Can I have overlapping device actions?"
    Yes, but with constraints. Different device types (olfactometers, MFCs, triggers) can have overlapping actions. However, the same device cannot have overlapping state changes, and valve assemblies cannot have overlapping preload windows.

??? question "How does randomization work?"
    When `randomize: true` is set for a phase with multi-state device actions, the system shuffles the state list using the configured seed. This ensures reproducible "randomization" - the same seed always produces the same sequence.

## Troubleshooting

??? question "Why do I get timing guardrail errors?"
    Guardrail errors occur when valve switching events are scheduled too close together. Check that your `preload_lead_ms` and `setup_hold_samples` settings provide sufficient margins between events. The error message will indicate which specific timing constraint was violated.

??? question "My MFC readings seem noisy - is this normal?"
    Some noise in MFC analog readings is normal. The system logs raw ADC values for full provenance. Consider the noise level relative to your experimental requirements and use appropriate filtering in post-analysis if needed.

??? question "Can I modify the protocol during execution?"
    No, protocols are compiled before execution and cannot be modified while running. This is by design to ensure complete reproducibility and data provenance. Stop the current run and start a new one with the modified protocol.

## Data and Analysis

??? question "Where is my data saved?"
    All run data is saved in timestamped directories under `data/runs/`. Each run includes the original protocol, compiled timing data, hardware logs, and any analog recordings.

??? question "What format is the logged data?"
    Data is saved in standard formats: YAML for configuration, NumPy arrays for timing data, and CSV for analog readings. This ensures compatibility with common analysis tools and long-term data accessibility.

??? question "How do I analyze the timing precision?"
    Use the interactive visualizer to examine the relationship between commanded and actual timing. The system logs both intended timing (from protocol) and actual hardware timing (from DAQ) for validation.

## Contributing and Support

??? question "I found a bug - how do I report it?"
    Please open an issue on the [GitHub repository](https://github.com/neurorishika/MultiBiOS) with details about your system, the protocol you were running, and the specific error or unexpected behavior.

??? question "Can I contribute new features?"
    Absolutely! See the [Contributing Guide](contributing.md) for information about the development process, coding standards, and how to submit pull requests.

??? question "Is there a user community?"
    The primary community is through GitHub issues and discussions. For neuroscience-specific questions, consider posting in relevant research forums with a link to this documentation.

---

!!! tip "Still have questions?"
    If you don't see your question here, check the detailed documentation sections or [open an issue](https://github.com/neurorishika/MultiBiOS/issues/new) on GitHub. We're happy to help!hy separate preload and commit?**  
A: It lets the DAQ timestamp the commit with hardware precision and coordinate multiple assemblies independently.

**Q: What does the guardrail prevent?**  
A: Overlapping “preload→commit” windows (where two assemblies would both be staged). The Teensy firmware intentionally handles exactly one staged owner at a time.

**Q: Why sticky S-bits?**  
A: They make digital rails represent **current state** between events, simplifying verification and downstream analysis.

**Q: Can I use 0.1 ms timing?**  
A: Yes; set `sample_rate: 10000` and ensure your USB-6353 and host can stream the sample count. Everything (guardrails, viewer) scales.

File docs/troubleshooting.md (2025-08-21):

# Troubleshooting

## Compile-time

- **Overlapping pre-load windows**
  - Error shows two labeled windows with times.
  - Increase spacing between commits, or increase `preload_lead_ms`.

- **Unknown device/channel**
  - Ensure the device key exists in `hardware.yaml` and matches schema expectations.

## Run-time

- **AI capture missing**
  - Check `analog_inputs` in `hardware.yaml`.
  - Ensure DO is master clock and AI slaves to `/<Dev>/do/SampleClock`.

- **No latching / valves don’t change**
  - Confirm DAQ actually toggles `*_LOAD_REQ` and `RCK_*`.
  - Confirm Teensy READY LEDs (optional pins) assert during preload and drop on RCK.
  - Verify level shifting to Teensy (3.3 V).

- **MFC feedback saturates**
  - Confirm `ai` voltage range (set ±10 V is fine for 0–5 V signals).
  - Check wiring and common ground.

- **Viewer shows nothing**
  - Open the run folder and check that `compiled_do.npz` and `preview.html` were created.

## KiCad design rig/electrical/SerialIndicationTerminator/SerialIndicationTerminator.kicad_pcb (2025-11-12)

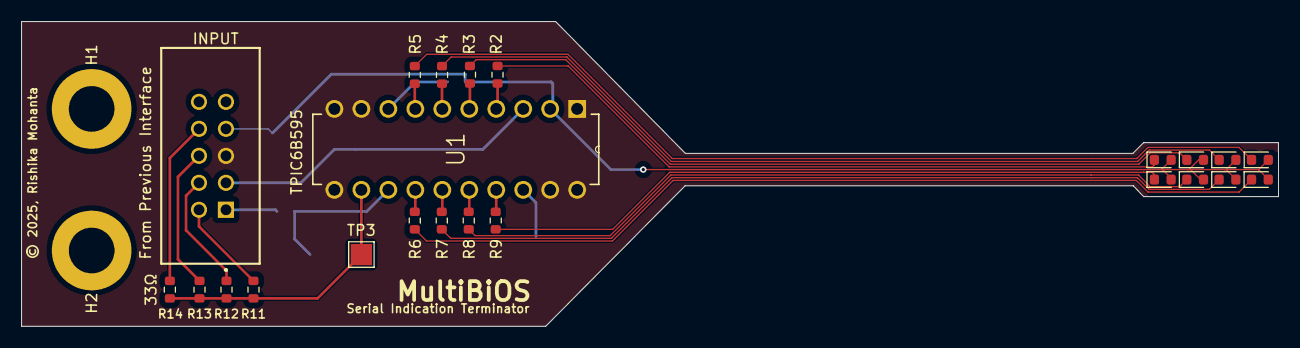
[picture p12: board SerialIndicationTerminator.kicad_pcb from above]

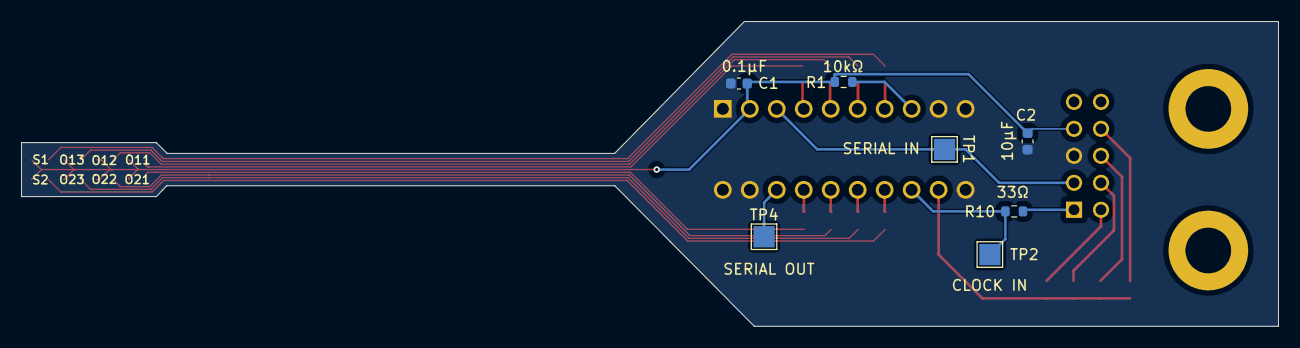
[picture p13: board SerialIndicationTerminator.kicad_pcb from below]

Board: 2 copper layers, 118.4 x 28.7 mm, 32 parts (7 on the bottom side), 28 nets.

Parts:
C1: 0.1u; C_0603_1608Metric
C2: 10uf; C_0603_1608Metric
D1, D2, D3, D4, D5, D6, D7, D8: LED; LED_0603_1608Metric
H1, H2: MountingHole; MountingHole_4.3mm_M4_DIN965_Pad
J1: TST-105-01-X-D; SAMTEC_TST-105-01-X-D
R1: 10k; R_0603_1608Metric
R2, R3, R4, R5, R6, R7, R8, R9: R; R_0603_1608Metric
R10, R11, R12, R13, R14: 33Ω; R_0603_1608Metric
TP1, TP2, TP3, TP4: TestPoint; TestPoint_Pad_2.0x2.0mm
U1: TPIC6595; DIP254P762X508-20

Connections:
+5V: C1.1, C2.1, D1.2 (A), D2.2 (A), D3.2 (A), D4.2 (A), D5.2 (A), D6.2 (A), D7.2 (A), D8.2 (A), J1.07, R1.2, U1.2 (VCC)
GND: C1.2, C2.2, J1.05, U1.1 (PGND), U1.9 (~G), U1.10 (PGND), U1.11 (PGND), U1.19 (LGND), U1.20 (PGND)
unnamed: D1.1 (K), R2.2
unnamed: D2.1 (K), R3.2
unnamed: D3.1 (K), R4.2
unnamed: D4.1 (K), R5.2
unnamed: D5.1 (K), R6.2
unnamed: D6.1 (K), R7.2
unnamed: D7.1 (K), R8.2
unnamed: D8.1 (K), R9.2
unnamed: J1.01, R10.1
unnamed: J1.02, R11.1
unnamed: J1.04, R12.1
unnamed: J1.06, R13.1
unnamed: J1.08, R14.1
unnamed: R2.1, U1.4 (DRAIN0)
unnamed: R3.1, U1.5 (DRAIN1)
unnamed: R4.1, U1.6 (DRAIN2)
unnamed: R5.1, U1.7 (DRAIN3)
unnamed: R6.1, U1.14 (DRAIN4)
unnamed: R7.1, U1.15 (DRAIN5)
unnamed: R8.1, U1.16 (DRAIN6)
unnamed: R9.1, U1.17 (DRAIN7)
unnamed: R11.2, R12.2, R13.2, R14.2, TP3.1, U1.12 (RCLK)
unnamed: J1.03, TP1.1, U1.3 (SER_IN)
unnamed: TP4.1, U1.18 (SER_OUT)
unnamed: R10.2, TP2.1, U1.13 (SRCK)
unnamed: R1.1, U1.8 (~SRCLR)

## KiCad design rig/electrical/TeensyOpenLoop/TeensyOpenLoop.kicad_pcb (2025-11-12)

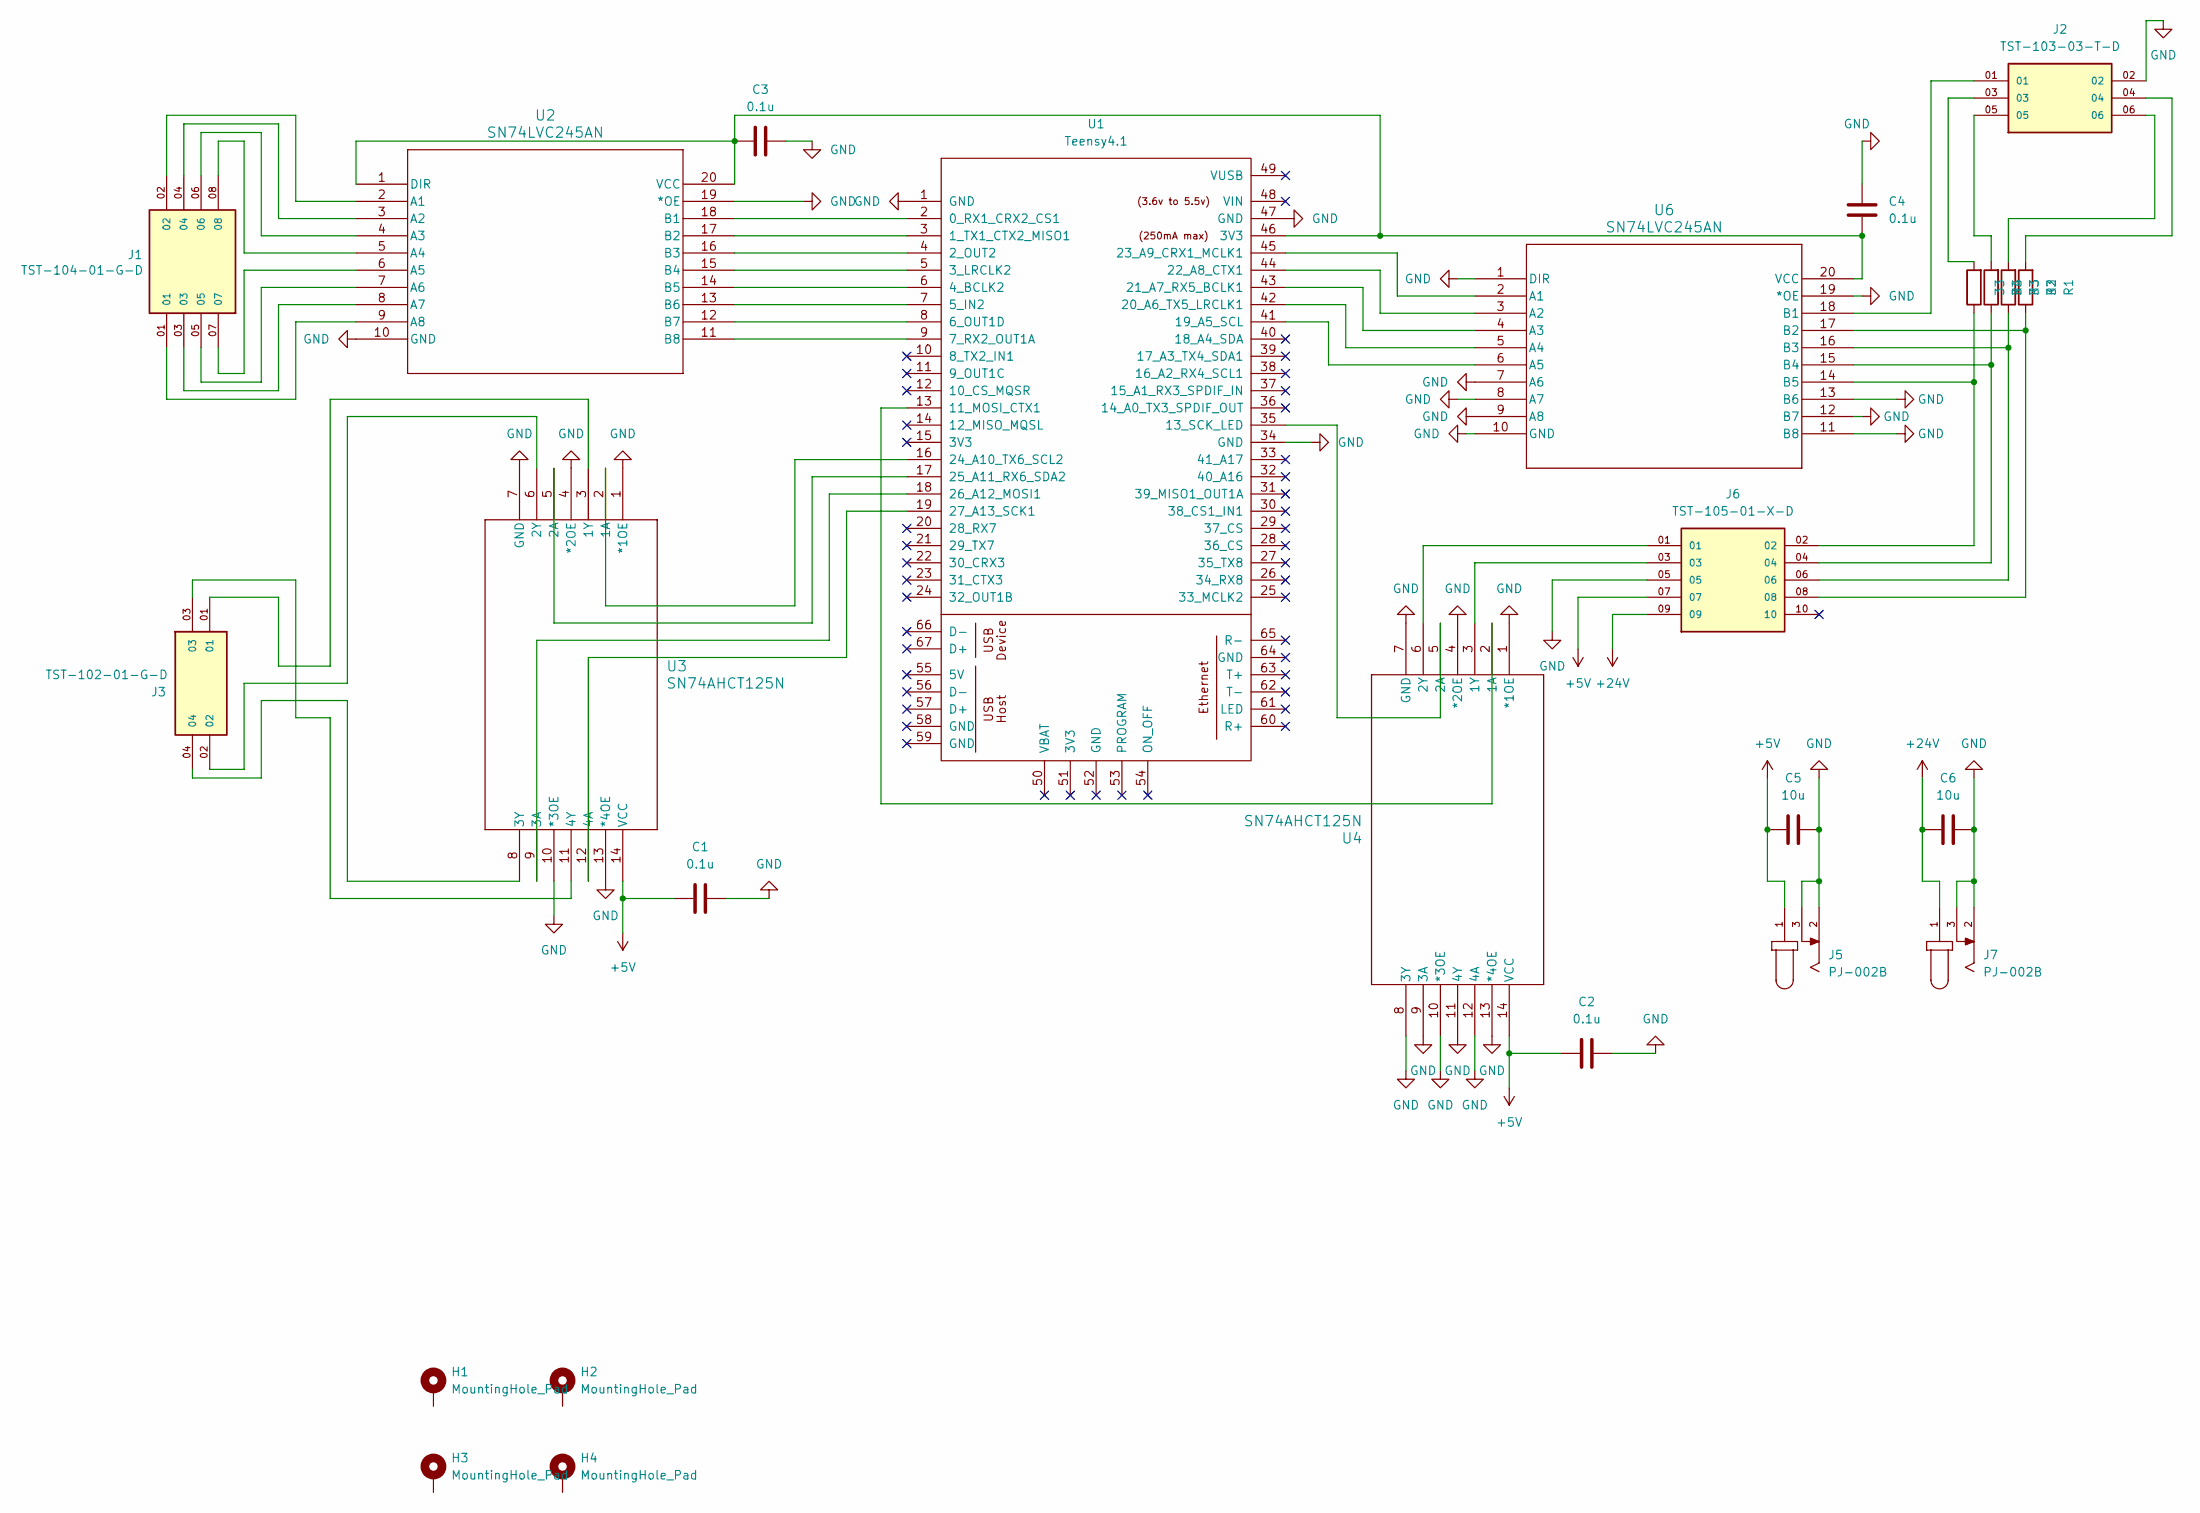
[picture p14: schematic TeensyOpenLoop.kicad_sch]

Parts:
C1, C2, C3, C4: 0.1u; C_0603_1608Metric
C5, C6: 10u; C_0603_1608Metric
H1, H2, H3, H4: MountingHole_Pad; MountingHole_3.2mm_M3_Pad
J1: TST-104-01-G-D; SAMTEC_TST-104-01-G-D; PARTREV R
J2: TST-103-03-T-D; SAMTEC_TST-103-03-T-D; PARTREV R
J3: TST-102-01-G-D; SAMTEC_TST-102-01-G-D; PARTREV R
J5, J7: PJ-002B; CUI_PJ-002B
J6: TST-105-01-X-D; SAMTEC_TST-105-01-X-D; PARTREV 1-23-96
R1, R2, R3, R4: 33; R_Axial_DIN0207_L6.3mm_D2.5mm_P10.16mm_Horizontal
U1: Teensy4.1; Teensy41
U2, U6: SN74LVC245AN; N20
U3, U4: SN74AHCT125N; N14

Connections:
+5V: C1.1, C2.1, C5.1, J5.1, J6.07, U3.14 (VCC), U4.14 (VCC)
+24V: C6.1, J6.09, J7.1
GND: C1.2, C2.2, C3.2, C4.1, C5.2, C6.2, J2.02, J5.2, J5.3, J6.05, J7.2, J7.3, U1.1 (GND), U1.34 (GND), U1.47 (GND), U2.10 (GND), U2.19 (*OE), U3.1 (*1OE), U3.4 (*2OE), U3.7 (GND), U3.10 (*3OE), U3.13 (*4OE), U4.1 (*1OE), U4.4 (*2OE), U4.7 (GND), U4.8 (3Y), U4.9 (3A), U4.10 (*3OE), U4.11 (4Y), U4.12 (4A), U4.13 (*4OE), U6.1 (DIR), U6.7 (A6), U6.8 (A7), U6.9 (A8), U6.10 (GND), U6.11 (B8), U6.12 (B7), U6.13 (B6), U6.19 (*OE)
unnamed: J2.03, R4.2
unnamed: J2.04, R1.2
unnamed: J2.05, R3.2
unnamed: J2.06, R2.2
unnamed: U1.2 (0_RX1_CRX2_CS1), U2.18 (B1)
unnamed: U1.3 (1_TX1_CTX2_MISO1), U2.17 (B2)
unnamed: U1.4 (2_OUT2), U2.16 (B3)
unnamed: U1.5 (3_LRCLK2), U2.15 (B4)
unnamed: U1.6 (4_BCLK2), U2.14 (B5)
unnamed: U1.7 (5_IN2), U2.13 (B6)
unnamed: U1.8 (6_OUT1D), U2.12 (B7)
unnamed: U1.9 (7_RX2_OUT1A), U2.11 (B8)
unnamed: U1.13 (11_MOSI_CTX1), U4.2 (1A)
unnamed: U1.35 (13_SCK_LED), U4.5 (2A)
unnamed: U1.41 (19_A5_SCL), U6.6 (A5)
unnamed: U1.42 (20_A6_TX5_LRCLK1), U6.5 (A4)
unnamed: U1.43 (21_A7_RX5_BCLK1), U6.4 (A3)
unnamed: U1.44 (22_A8_CTX1), U6.3 (A2)
unnamed: U1.45 (23_A9_CRX1_MCLK1), U6.2 (A1)
unnamed: U1.16 (24_A10_TX6_SCL2), U3.2 (1A)
unnamed: U1.17 (25_A11_RX6_SDA2), U3.5 (2A)
unnamed: U1.18 (26_A12_MOSI1), U3.9 (3A)
unnamed: U1.19 (27_A13_SCK1), U3.12 (4A)
unnamed: J1.02, U2.2 (A1)
unnamed: J1.04, U2.3 (A2)
unnamed: J1.06, U2.4 (A3)
unnamed: J1.08, U2.5 (A4)
unnamed: J1.07, U2.6 (A5)
unnamed: J1.05, U2.7 (A6)
unnamed: J1.03, U2.8 (A7)
unnamed: J1.01, U2.9 (A8)
unnamed: C3.1, C4.2, U1.46 (3V3), U2.1 (DIR), U2.20 (VCC), U6.20 (VCC)
unnamed: J3.01, U3.3 (1Y)
unnamed: J3.02, U3.6 (2Y)
unnamed: J3.04, U3.8 (3Y)
unnamed: J3.03, U3.11 (4Y)
unnamed: J6.03, U4.3 (1Y)
unnamed: J6.01, U4.6 (2Y)
unnamed: J2.01, U6.18 (B1)
unnamed: J6.08, R1.1, U6.17 (B2)
unnamed: J6.06, R2.1, U6.16 (B3)
unnamed: J6.04, R3.1, U6.15 (B4)
unnamed: J6.02, R4.1, U6.14 (B5)

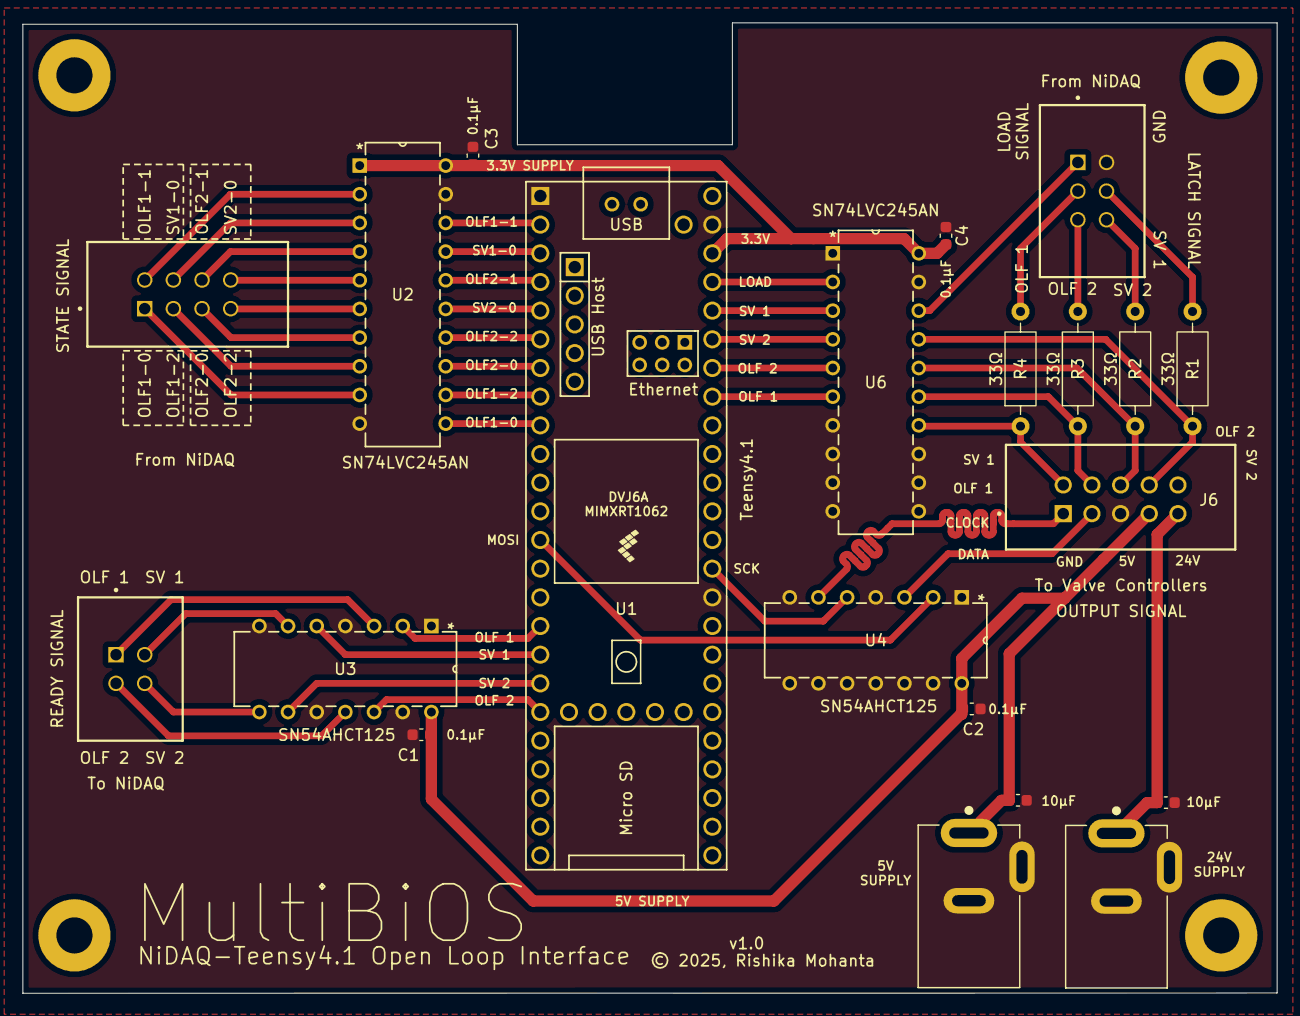
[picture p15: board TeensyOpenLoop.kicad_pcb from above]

Board: 2 copper layers, 111.1 x 86.0 mm, 25 parts (0 on the bottom side), 46 nets.

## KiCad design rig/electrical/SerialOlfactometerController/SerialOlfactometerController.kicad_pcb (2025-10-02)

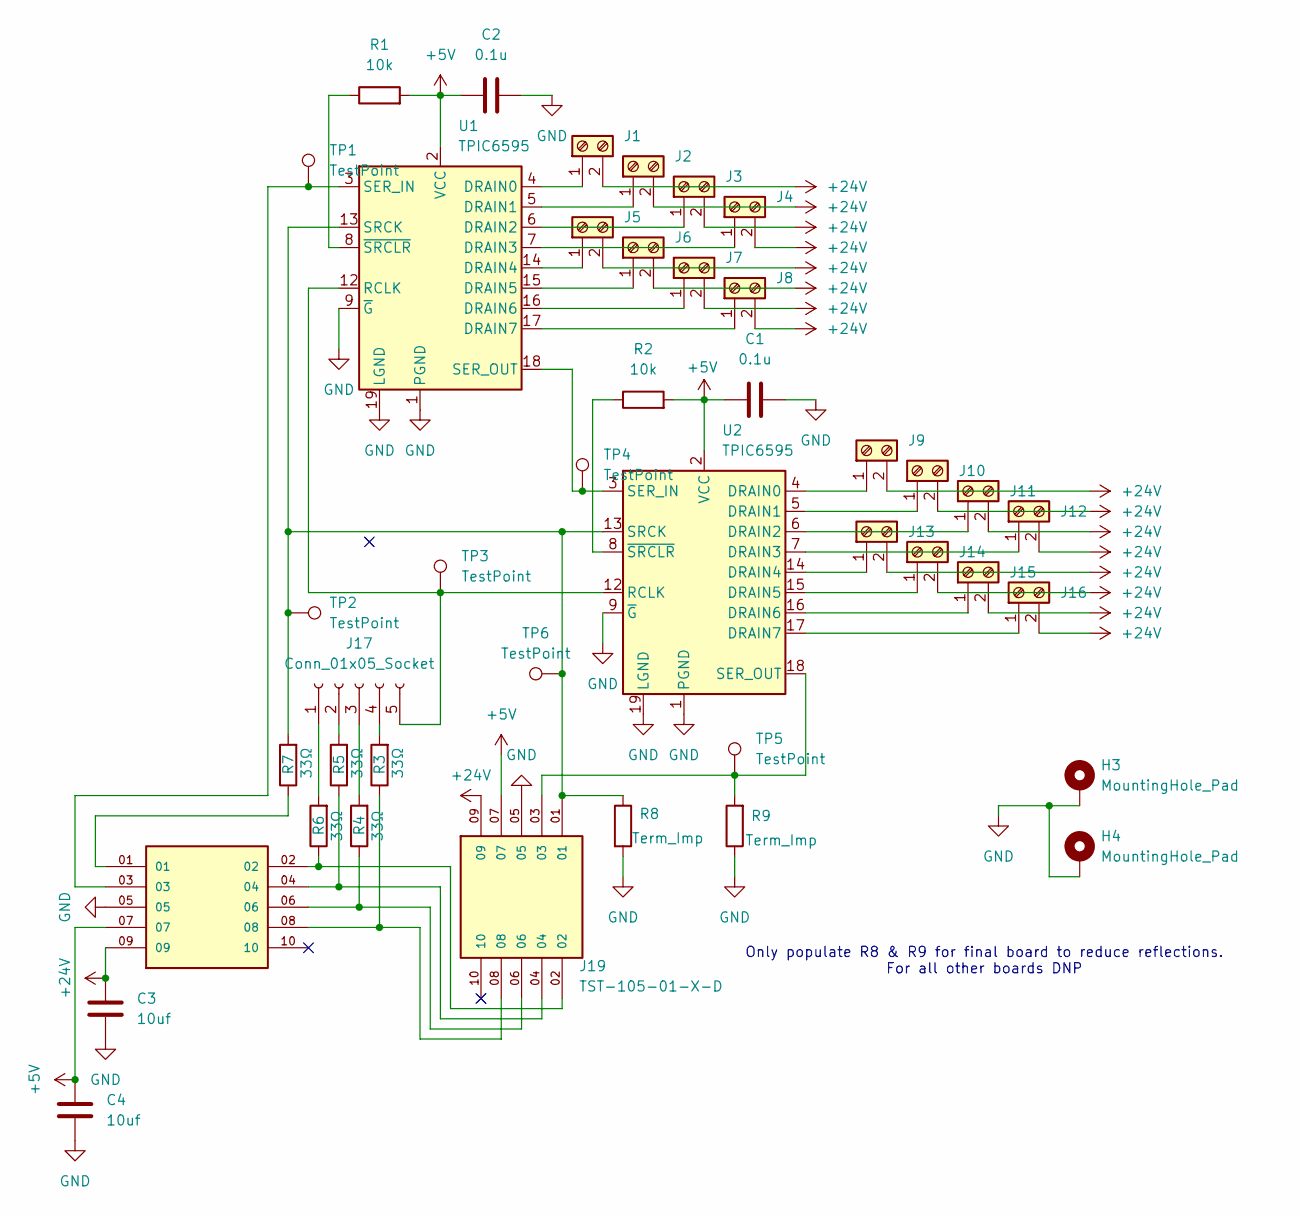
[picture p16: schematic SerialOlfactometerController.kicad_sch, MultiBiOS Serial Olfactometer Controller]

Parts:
C1, C2: 0.1u; C_0603_1608Metric
C3, C4: 10uf; C_0603_1608Metric
H3, H4: MountingHole_Pad; MountingHole_3.2mm_M3_Pad
J1, J2, J3, J4, J5, J6, J7, J8, J9, J10, J11, J12, J13, J14, J15, J16: Screw_Terminal_01x02; PHOENIX_1935310
J17: Conn_01x05_Socket; PinSocket_1x05_P2.54mm_Vertical
J18, J19: TST-105-01-X-D; SAMTEC_TST-105-01-X-D; PARTREV 1-23-96
R1, R2: 10k; R_0603_1608Metric
R3, R4, R5, R6, R7: 33Ω; R_0603_1608Metric
R8, R9: Term_Imp; R_0603_1608Metric
TP1, TP2, TP3, TP4, TP5, TP6: TestPoint; TestPoint_Pad_2.0x2.0mm
U1, U2: TPIC6595; DIP254P762X508-20

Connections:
+5V: C1.1, C2.1, C4.1, J18.07, J19.07, R1.2, R2.2, U1.2 (VCC), U2.2 (VCC)
+24V: C3.1, J1.2, J2.2, J3.2, J4.2, J5.2, J6.2, J7.2, J8.2, J9.2, J10.2, J11.2, J12.2, J13.2, J14.2, J15.2, J16.2, J18.09, J19.09
GND: C1.2, C2.2, C3.2, C4.2, H3.1, H4.1, J18.05, J19.05, R8.2, R9.1, U1.1 (PGND), U1.9 (~G), U1.10 (PGND), U1.11 (PGND), U1.19 (LGND), U1.20 (PGND), U2.1 (PGND), U2.9 (~G), U2.10 (PGND), U2.11 (PGND), U2.19 (LGND), U2.20 (PGND)
unnamed: J1.1, U1.4 (DRAIN0)
unnamed: J2.1, U1.5 (DRAIN1)
unnamed: J3.1, U1.6 (DRAIN2)
unnamed: J4.1, U1.7 (DRAIN3)
unnamed: J5.1, U1.14 (DRAIN4)
unnamed: J6.1, U1.15 (DRAIN5)
unnamed: J7.1, U1.16 (DRAIN6)
unnamed: J8.1, U1.17 (DRAIN7)
unnamed: J9.1, U2.4 (DRAIN0)
unnamed: J10.1, U2.5 (DRAIN1)
unnamed: J11.1, U2.6 (DRAIN2)
unnamed: J12.1, U2.7 (DRAIN3)
unnamed: J13.1, U2.14 (DRAIN4)
unnamed: J14.1, U2.15 (DRAIN5)
unnamed: J15.1, U2.16 (DRAIN6)
unnamed: J16.1, U2.17 (DRAIN7)
unnamed: J17.1, R6.2
unnamed: J17.2, R5.2
unnamed: J17.3, R4.2
unnamed: J17.4, R3.2
unnamed: J17.5, TP3.1, U1.12 (RCLK), U2.12 (RCLK)
unnamed: J18.01, R7.1
unnamed: J18.02, J19.02, R6.1
unnamed: J18.04, J19.04, R5.1
unnamed: J18.06, J19.06, R4.1
unnamed: J18.08, J19.08, R3.1
unnamed: J18.03, TP1.1, U1.3 (SER_IN)
unnamed: TP4.1, U1.18 (SER_OUT), U2.3 (SER_IN)
unnamed: J19.01, R7.2, R8.1, TP2.1, TP6.1, U1.13 (SRCK), U2.13 (SRCK)
unnamed: R1.1, U1.8 (~SRCLR)
unnamed: J19.03, R9.2, TP5.1, U2.18 (SER_OUT)
unnamed: R2.1, U2.8 (~SRCLR)

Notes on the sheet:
Only populate R8 & R9 for final board to reduce reflections. For all other boards DNP

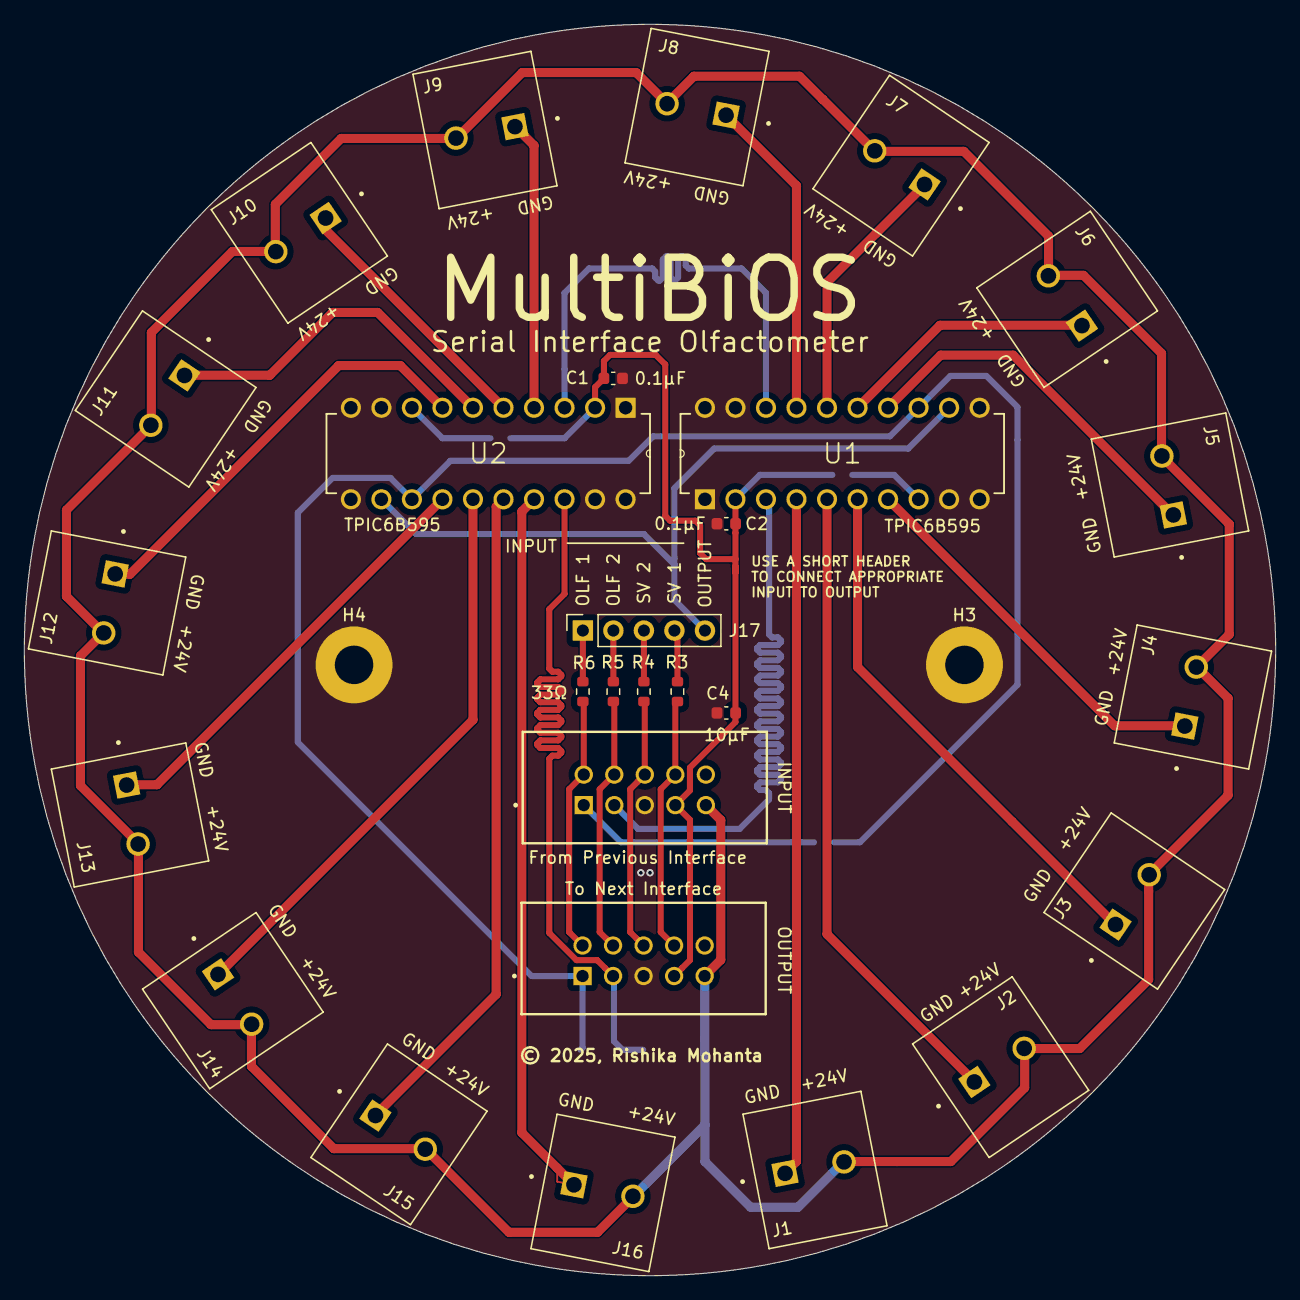
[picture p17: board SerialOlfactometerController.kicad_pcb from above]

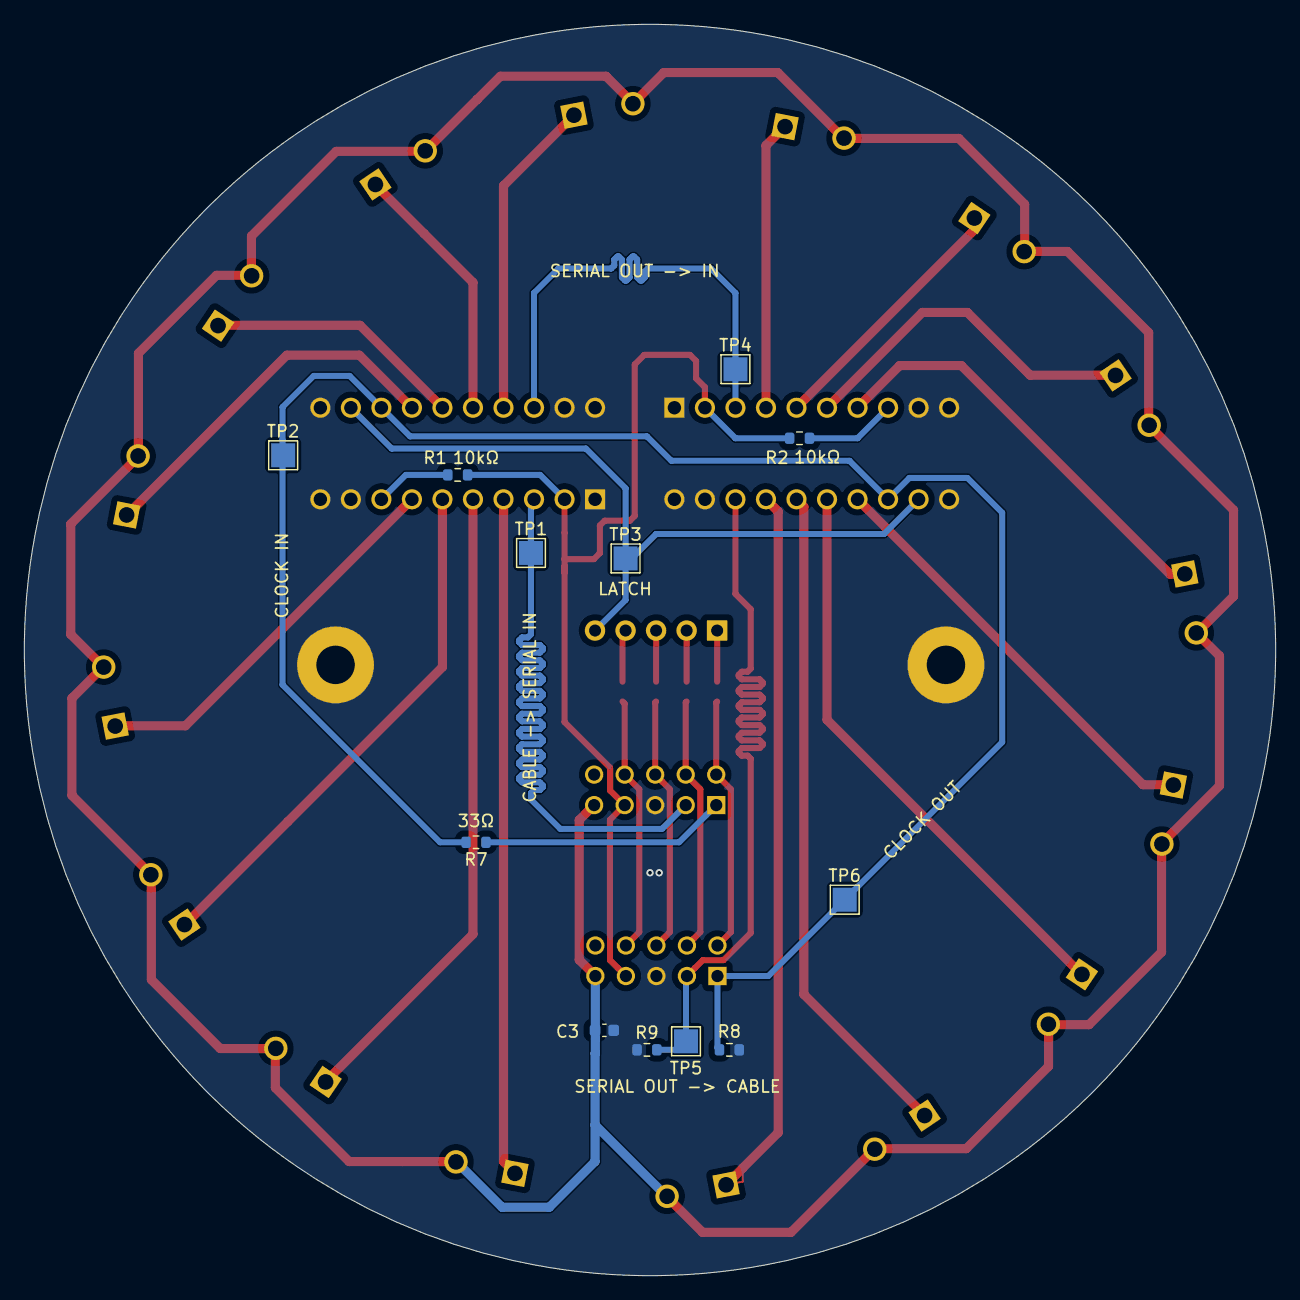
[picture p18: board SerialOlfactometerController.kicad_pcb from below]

Board: 2 copper layers, 104.1 x 104.1 mm, 42 parts (12 on the bottom side), 35 nets.

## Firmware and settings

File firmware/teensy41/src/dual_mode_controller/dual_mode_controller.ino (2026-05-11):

#include <Arduino.h>
#include <SPI.h>
#include <SD.h>
#include <stdarg.h>
#include <string.h>
#include <stdlib.h>

#ifndef BIT
#define BIT(n) (1u << (n))
#endif

// -------- Shared SPI --------
constexpr uint32_t SPI_HZ = 1'000'000;
constexpr int PIN_CS = 10;

// -------- Open-loop wiring --------
constexpr int PIN_S_OLF1_S1 = 0;
constexpr int PIN_S_SV1_S0  = 1;
constexpr int PIN_S_OLF2_S1 = 2;
constexpr int PIN_S_SV2_S0  = 3;
constexpr int PIN_S_OLF2_S2 = 4;
constexpr int PIN_S_OLF2_S0 = 5;
constexpr int PIN_S_OLF1_S2 = 6;
constexpr int PIN_S_OLF1_S0 = 7;

constexpr int PIN_GLOBAL_LOAD = 23;

constexpr int PIN_RCK_SENSE_OLF1 = 19;
constexpr int PIN_RCK_SENSE_OLF2 = 20;
constexpr int PIN_RCK_SENSE_SV2  = 21;
constexpr int PIN_RCK_SENSE_SV1  = 22;

constexpr int PIN_READY_OLF1 = 24;
constexpr int PIN_READY_SV1  = 25;
constexpr int PIN_READY_SV2  = 26;
constexpr int PIN_READY_OLF2 = 27;

// -------- Serial-mode command parsing --------
constexpr int MAX_CMD_BUF = 128;
constexpr int MAX_TOKENS = 12;

// -------- Shared frame map --------
enum FrameSlot : uint8_t {
  SLOT_OLF1_HI = 0,
  SLOT_OLF1_LO,
  SLOT_OLF2_HI,
  SLOT_OLF2_LO,
  SLOT_SV1,
  SLOT_SV2,
};

uint8_t FRAME_SEND_ORDER[6] = {
  SLOT_OLF1_LO,
  SLOT_OLF1_HI,
  SLOT_OLF2_LO,
  SLOT_OLF2_HI,
  SLOT_SV2,
  SLOT_SV1,
};

// -------- Minimal serial controller state --------
struct BitState {
  uint16_t olf1 = 0;
  uint16_t olf2 = 0;
  uint8_t sv1 = 0;
  uint8_t sv2 = 0;
};

BitState staged;
uint8_t stagedFrame[6] = {0, 0, 0, 0, 0, 0};
bool frameDirty = true;
uint8_t lastSentFrame[6] = {0, 0, 0, 0, 0, 0};

// -------- Open-loop logging --------
File logFile;
bool sdReady = false;
bool openLoopLogReady = false;
constexpr int LOG_BUFFER_SIZE = 64;
constexpr size_t LOG_LINE_MAX = 192;
volatile char logBuffer[LOG_BUFFER_SIZE][LOG_LINE_MAX];
volatile int logHead = 0;
volatile int logTail = 0;

// -------- Open-loop states --------
enum : uint8_t { ST_OFF = 0, ST_AIR, ST_ODOR1, ST_ODOR2, ST_ODOR3, ST_ODOR4, ST_ODOR5, ST_FLUSH };

constexpr uint16_t OLFACTOMETER_STATES[8] = {
  0x0000,
  BIT(0) | BIT(1),
  BIT(2) | BIT(3),
  BIT(4) | BIT(5),
  BIT(6) | BIT(7),
  BIT(8) | BIT(9),
  BIT(10) | BIT(11),
  (uint16_t)0x0FFF,
};

constexpr uint8_t SWITCH_STATES_2LVL[2] = {
  0b00000000,
  0b00000011,
};

enum FirmwareMode : uint8_t {
  MODE_SERIAL = 0,
  MODE_OPEN_LOOP = 1,
};

volatile FirmwareMode currentMode = MODE_SERIAL;
bool openLoopPinsInitialized = false;
bool openLoopInterruptsAttached = false;

volatile bool ready_olf1 = false;
volatile bool ready_olf2 = false;
volatile bool ready_sv1 = false;
volatile bool ready_sv2 = false;

// -------- Serial-mode TEST walker --------
constexpr uint8_t kTestBits[] = {
  0,1,2,3,4,5,6,7,8,9,10,11,
  16,17,18,19,20,21,22,23,24,25,26,27,
  32,33,
  40,41
};
constexpr uint8_t kTestBitCount = sizeof(kTestBits) / sizeof(kTestBits[0]);

struct TestWalker {
  bool active = false;
  bool onPhase = true;
  uint8_t idx = 0;
  uint32_t on_ms = 500;
  uint32_t off_ms = 500;
  elapsedMillis phaseTimer;
  uint8_t restoreFrame[6] = {0, 0, 0, 0, 0, 0};
};

TestWalker testWalker;
char cmdBuf[MAX_CMD_BUF];
int cmdLen = 0;

static inline void enqueue_logf(const char* fmt, ...) {
  int nextHead = (logHead + 1) % LOG_BUFFER_SIZE;
  if (nextHead == logTail) {
    return;
  }

  va_list args;
  va_start(args, fmt);
  vsnprintf((char*)logBuffer[logHead], LOG_LINE_MAX, fmt, args);
  va_end(args);
  logHead = nextHead;
}

static inline void bits_to_frame(const BitState& bits, uint8_t frame[6]) {
  frame[0] = (uint8_t)(bits.olf1 & 0xFF);
  frame[1] = (uint8_t)((bits.olf1 >> 8) & 0x0F);
  frame[2] = (uint8_t)(bits.olf2 & 0xFF);
  frame[3] = (uint8_t)((bits.olf2 >> 8) & 0x0F);
  frame[4] = (uint8_t)(bits.sv2 & 0x03);
  frame[5] = (uint8_t)(bits.sv1 & 0x03);
}

static inline void frame_to_bits(const uint8_t frame[6], BitState& bits) {
  bits.olf1 = frame[0] | ((uint16_t)(frame[1] & 0x0F) << 8);
  bits.olf2 = frame[2] | ((uint16_t)(frame[3] & 0x0F) << 8);
  bits.sv2 = frame[4] & 0x03;
  bits.sv1 = frame[5] & 0x03;
}

static inline void rebuild_staged_frame() {
  bits_to_frame(staged, stagedFrame);
  frameDirty = false;
}

static inline void mark_dirty() {
  frameDirty = true;
}

static inline void spi_send_raw(const uint8_t frame[6]) {
  SPI.beginTransaction(SPISettings(SPI_HZ, MSBFIRST, SPI_MODE0));
  for (int i = 5; i >= 0; --i) {
    SPI.transfer(frame[i]);
  }
  SPI.endTransaction();
}

static void print_frame_hex(const uint8_t frame[6]) {
  for (int i = 5; i >= 0; --i) {
    if (frame[i] < 0x10) {
      Serial.print('0');
    }
    Serial.print(frame[i], HEX);
    if (i > 0) {
      Serial.print(' ');
    }
  }
  Serial.println();
}

static void print_state_line(const uint8_t frame[6]) {
  BitState bits;
  frame_to_bits(frame, bits);
  char buf[34];
  int pos = 0;
  for (int i = 11; i >= 0; --i) buf[pos++] = ((bits.olf1 >> i) & 1) ? '1' : '0';
  buf[pos++] = ' ';
  for (int i = 11; i >= 0; --i) buf[pos++] = ((bits.olf2 >> i) & 1) ? '1' : '0';
  buf[pos++] = ' ';
  for (int i = 1; i >= 0; --i) buf[pos++] = ((bits.sv1 >> i) & 1) ? '1' : '0';
  buf[pos++] = ' ';
  for (int i = 1; i >= 0; --i) buf[pos++] = ((bits.sv2 >> i) & 1) ? '1' : '0';
  buf[pos] = '\0';
  Serial.println(buf);
}

static void do_send_frame(const uint8_t frame[6], const char* label) {
  spi_send_raw(frame);
  Serial.print(label);
  Serial.print(" Data: ");
  print_frame_hex(frame);
  memcpy(lastSentFrame, frame, 6);
}

static void do_send_staged() {
  if (frameDirty) {
    rebuild_staged_frame();
  }
  do_send_frame(stagedFrame, "SEND");
}

static bool is_numeric(const char* text) {
  if (!text || !*text) {
    return false;
  }
  const char* cursor = text;
  if (*cursor == '-') {
    ++cursor;
  }
  if (!*cursor) {
    return false;
  }
  for (; *cursor; ++cursor) {
    if (*cursor < '0' || *cursor > '9') {
      return false;
    }
  }
  return true;
}

static void str_upper(char* text) {
  for (; *text; ++text) {
    if (*text >= 'a' && *text <= 'z') {
      *text -= 32;
    }
  }
}

static bool parse_olf_cmd(const char* cmd, uint8_t& firstBit) {
  if (strcmp(cmd, "CTRL") == 0) {
    firstBit = 0;
    return true;
  }
  if (strlen(cmd) == 3 && cmd[0] == 'O' && cmd[1] == 'D' && cmd[2] >= '1' && cmd[2] <= '5') {
    firstBit = (uint8_t)(2 * (cmd[2] - '0'));
    return true;
  }
  return false;
}

static bool parse_olf_target(const char* text, bool& olf1, bool& olf2) {
  if (strcmp(text, "OLF1") == 0) {
    olf1 = true;
    olf2 = false;
    return true;
  }
  if (strcmp(text, "OLF2") == 0) {
    olf1 = false;
    olf2 = true;
    return true;
  }
  if (strcmp(text, "ALL") == 0) {
    olf1 = true;
    olf2 = true;
    return true;
  }
  return false;
}

static bool parse_sv_target(const char* text, bool& sv1, bool& sv2) {
  if (strcmp(text, "SV1") == 0) {
    sv1 = true;
    sv2 = false;
    return true;
  }
  if (strcmp(text, "SV2") == 0) {
    sv1 = false;
    sv2 = true;
    return true;
  }
  if (strcmp(text, "ALL") == 0) {
    sv1 = true;
    sv2 = true;
    return true;
  }
  return false;
}

static void olf_set_pair(BitState& bits, bool setOlf1, bool setOlf2, uint8_t firstBit) {
  uint16_t value = 0;
  if (firstBit < 12) value |= (1u << firstBit);
  if (firstBit + 1 < 12) value |= (1u << (firstBit + 1));
  if (setOlf1) bits.olf1 = value;
  if (setOlf2) bits.olf2 = value;
}

static void stop_test(bool announce) {
  if (!testWalker.active) {
    return;
  }
  testWalker.active = false;
  do_send_frame(testWalker.restoreFrame, "TEST STOP restore");
  memcpy(stagedFrame, testWalker.restoreFrame, 6);
  frame_to_bits(testWalker.restoreFrame, staged);
  frameDirty = false;
  if (announce) {
    Serial.println("TEST STOP OK");
  }
}

static void preempt_test() {
  if (testWalker.active) {
    stop_test(false);
    Serial.println("TEST preempted");
  }
}

static void test_send_one_hot(uint8_t absBit) {
  uint8_t frame[6] = {0, 0, 0, 0, 0, 0};
  uint8_t byteIdx = absBit / 8;
  uint8_t bitInByte = absBit % 8;
  if (byteIdx < 6) {
    frame[byteIdx] = (uint8_t)(1u << bitInByte);
  }
  char label[24];
  snprintf(label, sizeof(label), "TEST bit%u", absBit);
  do_send_frame(frame, label);
}

static void test_send_zero() {
  uint8_t frame[6] = {0, 0, 0, 0, 0, 0};
  do_send_frame(frame, "TEST gap");
}

static void start_test(uint32_t onMs, uint32_t offMs) {
  preempt_test();
  if (frameDirty) {
    rebuild_staged_frame();
  }
  memcpy(testWalker.restoreFrame, stagedFrame, 6);
  testWalker.active = true;
  testWalker.onPhase = true;
  testWalker.idx = 0;
  testWalker.on_ms = onMs;
  testWalker.off_ms = offMs;
  testWalker.phaseTimer = 0;
  test_send_one_hot(kTestBits[0]);
}

static void init_open_loop_pins() {
  if (openLoopPinsInitialized) {
    return;
  }

  pinMode(PIN_READY_OLF1, OUTPUT); digitalWriteFast(PIN_READY_OLF1, LOW);
  pinMode(PIN_READY_SV1, OUTPUT);  digitalWriteFast(PIN_READY_SV1, LOW);
  pinMode(PIN_READY_SV2, OUTPUT);  digitalWriteFast(PIN_READY_SV2, LOW);
  pinMode(PIN_READY_OLF2, OUTPUT); digitalWriteFast(PIN_READY_OLF2, LOW);

  pinMode(PIN_S_OLF1_S1, INPUT);
  pinMode(PIN_S_SV1_S0, INPUT);
  pinMode(PIN_S_OLF2_S1, INPUT);
  pinMode(PIN_S_SV2_S0, INPUT);
  pinMode(PIN_S_OLF2_S2, INPUT);
  pinMode(PIN_S_OLF2_S0, INPUT);
  pinMode(PIN_S_OLF1_S2, INPUT);
  pinMode(PIN_S_OLF1_S0, INPUT);

  pinMode(PIN_GLOBAL_LOAD, INPUT);
  pinMode(PIN_RCK_SENSE_OLF1, INPUT);
  pinMode(PIN_RCK_SENSE_OLF2, INPUT);
  pinMode(PIN_RCK_SENSE_SV2, INPUT);
  pinMode(PIN_RCK_SENSE_SV1, INPUT);

  openLoopPinsInitialized = true;
}

static bool init_open_loop_logging() {
  if (openLoopLogReady) {
    return true;
  }

  if (!sdReady) {
    if (!SD.begin(BUILTIN_SDCARD)) {
      Serial.println("FAULT code=SD_INIT_FAILED action=OPENLOOP_ABORT");
      return false;
    }
    sdReady = true;
    Serial.println("MODE sd_card=ready");
  }

  char logFileName[] = "log_000.txt";
  for (int i = 0; i < 1000; ++i) {
    logFileName[4] = i / 100 + '0';
    logFileName[5] = (i / 10) % 10 + '0';
    logFileName[6] = i % 10 + '0';
    if (!SD.exists(logFileName)) {
      break;
    }
  }

  logFile = SD.open(logFileName, FILE_WRITE);
  if (!logFile) {
    Serial.println("FAULT code=LOG_OPEN_FAILED action=OPENLOOP_ABORT");
    return false;
  }

  openLoopLogReady = true;
  Serial.print("MODE log_file=");
  Serial.println(logFileName);
  logFile.println("MODE name=open_loop_controller version=1 transport=usb_serial");
  logFile.flush();
  return true;
}

static inline void build_open_loop_frame(uint8_t out[6]) {
  uint8_t olf1_idx = ((digitalReadFast(PIN_S_OLF1_S2) & 1) << 2) |
                     ((digitalReadFast(PIN_S_OLF1_S1) & 1) << 1) |
                     ((digitalReadFast(PIN_S_OLF1_S0) & 1) << 0);
  uint8_t olf2_idx = ((digitalReadFast(PIN_S_OLF2_S2) & 1) << 2) |
                     ((digitalReadFast(PIN_S_OLF2_S1) & 1) << 1) |
                     ((digitalReadFast(PIN_S_OLF2_S0) & 1) << 0);
  uint8_t sv1_idx = (digitalReadFast(PIN_S_SV1_S0) & 1);
  uint8_t sv2_idx = (digitalReadFast(PIN_S_SV2_S0) & 1);

  uint16_t olf1_val = OLFACTOMETER_STATES[olf1_idx & 0x07];
  uint16_t olf2_val = OLFACTOMETER_STATES[olf2_idx & 0x07];
  uint8_t sv1_val = SWITCH_STATES_2LVL[sv1_idx & 0x01];
  uint8_t sv2_val = SWITCH_STATES_2LVL[sv2_idx & 0x01];

  uint8_t slots[6];
  slots[SLOT_OLF1_HI] = (uint8_t)((olf1_val >> 8) & 0xFF);
  slots[SLOT_OLF1_LO] = (uint8_t)(olf1_val & 0xFF);
  slots[SLOT_OLF2_HI] = (uint8_t)((olf2_val >> 8) & 0xFF);
  slots[SLOT_OLF2_LO] = (uint8_t)(olf2_val & 0xFF);
  slots[SLOT_SV1] = sv1_val;
  slots[SLOT_SV2] = sv2_val;

  for (int i = 0; i < 6; ++i) {
    out[i] = slots[FRAME_SEND_ORDER[i]];
  }

  unsigned long t = micros();
  enqueue_logf(
    "VALVE t_us=%lu olf1_state=%u olf2_state=%u sv1_state=%u sv2_state=%u olf1_bits=0x%04X olf2_bits=0x%04X sv1_bits=0x%02X sv2_bits=0x%02X",
    t, olf1_idx, olf2_idx, sv1_idx, sv2_idx, olf1_val, olf2_val, sv1_val, sv2_val
  );
}

static void attach_open_loop_interrupts();
static void detach_open_loop_interrupts();

void isr_global_load() {
  if (currentMode != MODE_OPEN_LOOP) {
    return;
  }
  uint8_t bytes[6];
  build_open_loop_frame(bytes);
  spi_send_raw(bytes);

  ready_olf1 = ready_olf2 = ready_sv1 = ready_sv2 = true;
  digitalWriteFast(PIN_READY_OLF1, HIGH);
  digitalWriteFast(PIN_READY_OLF2, HIGH);
  digitalWriteFast(PIN_READY_SV1, HIGH);
  digitalWriteFast(PIN_READY_SV2, HIGH);
  enqueue_logf("READY t_us=%lu target=ALL olf1=1 olf2=1 sv1=1 sv2=1 reason=LOAD", micros());
}

void isr_rck_olf1() {
  if (currentMode != MODE_OPEN_LOOP || !ready_olf1) {
    return;
  }
  ready_olf1 = false;
  digitalWriteFast(PIN_READY_OLF1, LOW);
  unsigned long t = micros();
  enqueue_logf("COMMIT t_us=%lu target=OLF1", t);
  enqueue_logf("READY t_us=%lu target=OLF1 value=0 reason=RCK", t);
}

void isr_rck_olf2() {
  if (currentMode != MODE_OPEN_LOOP || !ready_olf2) {
    return;
  }
  ready_olf2 = false;
  digitalWriteFast(PIN_READY_OLF2, LOW);
  unsigned long t = micros();
  enqueue_logf("COMMIT t_us=%lu target=OLF2", t);
  enqueue_logf("READY t_us=%lu target=OLF2 value=0 reason=RCK", t);
}

void isr_rck_sv2() {
  if (currentMode != MODE_OPEN_LOOP || !ready_sv2) {
    return;
  }
  ready_sv2 = false;
  digitalWriteFast(PIN_READY_SV2, LOW);
  unsigned long t = micros();
  enqueue_logf("COMMIT t_us=%lu target=SV2", t);
  enqueue_logf("READY t_us=%lu target=SV2 value=0 reason=RCK", t);
}

void isr_rck_sv1() {
  if (currentMode != MODE_OPEN_LOOP || !ready_sv1) {
    return;
  }
  ready_sv1 = false;
  digitalWriteFast(PIN_READY_SV1, LOW);
  unsigned long t = micros();
  enqueue_logf("COMMIT t_us=%lu target=SV1", t);
  enqueue_logf("READY t_us=%lu target=SV1 value=0 reason=RCK", t);
}

static void attach_open_loop_interrupts() {
  if (openLoopInterruptsAttached) {
    return;
  }
  attachInterrupt(digitalPinToInterrupt(PIN_GLOBAL_LOAD), isr_global_load, RISING);
  attachInterrupt(digitalPinToInterrupt(PIN_RCK_SENSE_OLF1), isr_rck_olf1, RISING);
  attachInterrupt(digitalPinToInterrupt(PIN_RCK_SENSE_OLF2), isr_rck_olf2, RISING);
  attachInterrupt(digitalPinToInterrupt(PIN_RCK_SENSE_SV2), isr_rck_sv2, RISING);
  attachInterrupt(digitalPinToInterrupt(PIN_RCK_SENSE_SV1), isr_rck_sv1, RISING);
  openLoopInterruptsAttached = true;
}

static void detach_open_loop_interrupts() {
  if (!openLoopInterruptsAttached) {
    return;
  }
  detachInterrupt(digitalPinToInterrupt(PIN_GLOBAL_LOAD));
  detachInterrupt(digitalPinToInterrupt(PIN_RCK_SENSE_OLF1));
  detachInterrupt(digitalPinToInterrupt(PIN_RCK_SENSE_OLF2));
  detachInterrupt(digitalPinToInterrupt(PIN_RCK_SENSE_SV2));
  detachInterrupt(digitalPinToInterrupt(PIN_RCK_SENSE_SV1));
  openLoopInterruptsAttached = false;
}

static void enter_open_loop_mode() {
  if (currentMode == MODE_OPEN_LOOP) {
    Serial.println("OPENLOOP already active");
    return;
  }

  preempt_test();
  init_open_loop_pins();
  if (!init_open_loop_logging()) {
    return;
  }

  ready_olf1 = ready_olf2 = ready_sv1 = ready_sv2 = false;
  digitalWriteFast(PIN_READY_OLF1, LOW);
  digitalWriteFast(PIN_READY_OLF2, LOW);
  digitalWriteFast(PIN_READY_SV1, LOW);
  digitalWriteFast(PIN_READY_SV2, LOW);

  currentMode = MODE_OPEN_LOOP;
  attach_open_loop_interrupts();

  uint8_t initBytes[6] = {0, 0, 0, 0, 0, 0};
  spi_send_raw(initBytes);

  Serial.println("MODE name=open_loop_controller version=1 transport=usb_serial");
  enqueue_logf("VALVE t_us=%lu olf1_state=0 olf2_state=0 sv1_state=0 sv2_state=0 reason=BOOT_INIT", micros());
  enqueue_logf("READY t_us=%lu target=ALL olf1=0 olf2=0 sv1=0 sv2=0 reason=BOOT", micros());
  enqueue_logf("MODE t_us=%lu state=OPEN_LOOP reason=CMD_START", micros());
  Serial.println("OPENLOOP START OK");
}

static void exit_open_loop_mode() {
  if (currentMode != MODE_OPEN_LOOP) {
    Serial.println("OPENLOOP already stopped");
    return;
  }

  detach_open_loop_interrupts();
  currentMode = MODE_SERIAL;

  ready_olf1 = ready_olf2 = ready_sv1 = ready_sv2 = false;
  digitalWriteFast(PIN_READY_OLF1, LOW);
  digitalWriteFast(PIN_READY_OLF2, LOW);
  digitalWriteFast(PIN_READY_SV1, LOW);
  digitalWriteFast(PIN_READY_SV2, LOW);

  enqueue_logf("MODE t_us=%lu state=SERIAL reason=CMD_STOP", micros());
  do_send_staged();
  Serial.println("OPENLOOP STOP OK");
}

static void print_help() {
  Serial.println(F(
    "Commands:\n"
    "  CTRL <OLF1|OLF2|ALL>\n"
    "  OD1..OD5 <OLF1|OLF2|ALL>\n"
    "  STOP <SV1|SV2|ALL>\n"
    "  STIM <SV1|SV2|ALL>\n"
    "  RESET\n"
    "  TEST START [on_ms [off_ms]]\n"
    "  TEST STOP\n"
    "  PRINT | STATE\n"
    "  OPENLOOP START\n"
    "  OPENLOOP STOP"
  ));
}

static void print_status() {
  Serial.print("MODE: ");
  Serial.println(currentMode == MODE_OPEN_LOOP ? "OPEN_LOOP" : "SERIAL");
  if (frameDirty) {
    rebuild_staged_frame();
  }
  Serial.print("STATE: ");
  print_state_line(stagedFrame);
  Serial.print("TEST: ");
  Serial.println(testWalker.active ? "ACTIVE" : "idle");
}

static void handle_command(char* rawLine) {
  while (*rawLine == ' ' || *rawLine == '\t') {
    ++rawLine;
  }
  if (!*rawLine) {
    return;
  }

  str_upper(rawLine);

  char* tok[MAX_TOKENS];
  int ntok = 0;
  char* token = strtok(rawLine, " \t");
  while (token && ntok < MAX_TOKENS) {
    tok[ntok++] = token;
    token = strtok(nullptr, " \t");
  }
  if (ntok == 0) {
    return;
  }

  const char* cmd = tok[0];

  if (strcmp(cmd, "HELP") == 0) {
    print_help();
    return;
  }

  if (strcmp(cmd, "STATUS") == 0) {
    print_status();
    return;
  }

  if (strcmp(cmd, "OPENLOOP") == 0) {
    if (ntok < 2) {
      Serial.println("ERR: OPENLOOP START|STOP");
      return;
    }
    if (strcmp(tok[1], "START") == 0) {
      enter_open_loop_mode();
      return;
    }
    if (strcmp(tok[1], "STOP") == 0) {
      exit_open_loop_mode();
      return;
    }
    Serial.println("ERR: OPENLOOP START|STOP");
    return;
  }

  if (currentMode == MODE_OPEN_LOOP) {
    Serial.println("ERR: open-loop mode active; use OPENLOOP STOP");
    return;
  }

  if (strcmp(cmd, "PRINT") == 0 || strcmp(cmd, "STATE") == 0) {
    if (frameDirty) {
      rebuild_staged_frame();
    }
    Serial.print("STATE: ");
    print_state_line(stagedFrame);
    return;
  }

  if (strcmp(cmd, "RESET") == 0) {
    preempt_test();
    staged = {0, 0, 0, 0};
    mark_dirty();
    do_send_staged();
    Serial.println("RESET OK");
    return;
  }

  if (strcmp(cmd, "TEST") == 0) {
    if (ntok < 2) {
      Serial.println("ERR: TEST START|STOP");
      return;
    }
    if (strcmp(tok[1], "START") == 0) {
      uint32_t onMs = (ntok >= 3 && is_numeric(tok[2])) ? (uint32_t)atol(tok[2]) : 500;
      uint32_t offMs = (ntok >= 4 && is_numeric(tok[3])) ? (uint32_t)atol(tok[3]) : 500;
      start_test(onMs, offMs);
      Serial.print("TEST START on=");
      Serial.print(onMs);
      Serial.print(" off=");
      Serial.println(offMs);
      return;
    }
    if (strcmp(tok[1], "STOP") == 0) {
      stop_test(true);
      return;
    }
    Serial.println("ERR: TEST START|STOP");
    return;
  }

  if (strcmp(cmd, "STOP") == 0 || strcmp(cmd, "STIM") == 0) {
    if (ntok < 2) {
      Serial.println("ERR: STOP/STIM needs SV1|SV2|ALL");
      return;
    }
    preempt_test();
    bool toClean = (strcmp(cmd, "STOP") == 0);
    bool sv1 = false;
    bool sv2 = false;
    if (!parse_sv_target(tok[1], sv1, sv2)) {
      Serial.println("ERR: bad switch target");
      return;
    }
    if (sv1) staged.sv1 = toClean ? 0x00 : 0x03;
    if (sv2) staged.sv2 = toClean ? 0x00 : 0x03;
    mark_dirty();
    do_send_staged();
    Serial.print(cmd);
    Serial.print(' ');
    Serial.print(tok[1]);
    Serial.println(" OK");
    return;
  }

  uint8_t firstBit;
  if (parse_olf_cmd(cmd, firstBit)) {
    if (ntok < 2) {
      Serial.println("ERR: needs OLF1|OLF2|ALL");
      return;
    }
    preempt_test();
    bool olf1 = false;
    bool olf2 = false;
    if (!parse_olf_target(tok[1], olf1, olf2)) {
      Serial.println("ERR: bad OLF target");
      return;
    }
    olf_set_pair(staged, olf1, olf2, firstBit);
    mark_dirty();
    do_send_staged();
    Serial.print(cmd);
    Serial.print(' ');
    Serial.print(tok[1]);
    Serial.println(" OK");
    return;
  }

  Serial.print("ERR: unknown command '");
  Serial.print(cmd);
  Serial.println("'");
}

void setup() {
  Serial.begin(115200);
  delay(300);
  Serial.println("=== TPIC6B595 controller v2 (Teensy 4.1) ===");
  Serial.println("Type HELP for commands. HB ON to enable heartbeat.");
  Serial.println("OPENLOOP START switches to DAQ-driven open-loop mode.");

  pinMode(PIN_CS, OUTPUT);
  SPI.begin();
}

static void process_serial_input() {
  while (Serial.available()) {
    char c = (char)Serial.read();
    if (c == '\r') {
      continue;
    }
    if (c == '\n') {
      cmdBuf[cmdLen] = '\0';
      handle_command(cmdBuf);
      cmdLen = 0;
    } else if (cmdLen < MAX_CMD_BUF - 1) {
      cmdBuf[cmdLen++] = c;
    }
  }
}

static void process_test_walker() {
  if (!testWalker.active || currentMode != MODE_SERIAL) {
    return;
  }

  if (testWalker.onPhase) {
    if (testWalker.phaseTimer >= testWalker.on_ms) {
      testWalker.onPhase = false;
      testWalker.phaseTimer = 0;
      test_send_zero();
    }
  } else if (testWalker.phaseTimer >= testWalker.off_ms) {
    testWalker.onPhase = true;
    testWalker.phaseTimer = 0;
    ++testWalker.idx;
    if (testWalker.idx >= kTestBitCount) {
      testWalker.idx = 0;
    }
    test_send_one_hot(kTestBits[testWalker.idx]);
  }
}

static void drain_logs() {
  if (logHead == logTail) {
    return;
  }

  noInterrupts();
  int idx = logTail;
  interrupts();

  Serial.println((char*)logBuffer[idx]);
  if (logFile) {
    logFile.println((char*)logBuffer[idx]);
    logFile.flush();
  }

  noInterrupts();
  logTail = (logTail + 1) % LOG_BUFFER_SIZE;
  interrupts();
}

void loop() {
  process_serial_input();
  process_test_walker();
  drain_logs();
}

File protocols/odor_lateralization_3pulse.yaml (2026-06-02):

# ==============================================================
#  ODOR LATERALIZATION PROTOCOL  —  3-PULSE VARIANT
#  Tests 5 conditions: bilateral, left-only, right-only,
#  left->right (15 s overlap window), right->left (15 s overlap window).
#
#  Each trial: 3 × (5 s ON / 5 s OFF) pulses per side.
#  Total active pulse window per side = 25 s.
#  Overlap trials: right side offset by 10 s, giving a
#  15 s temporal-overlap window (simultaneous odor at 10–15 s
#  and 20–25 s = 10 s of concurrent delivery).
#
#  ┌─────────────────────────────────────────────────────┐
#  │  CHANGE THE ODOR HERE (one place, applies to all)   │
#  │  Options: ODOR1  ODOR2  ODOR3  ODOR4  ODOR5  FLUSH  │
#  └─────────────────────────────────────────────────────┘
_active_odor: &odor "ODOR1"
_mfc_odor_flow_slpm: &mfc_flow 0.3
# ==============================================================

protocol:
  name: "Odor Lateralization 3-Pulse"
  version: "1.0"
  description: >
    Olfactometer switches to odor and saturates for 60 s.
    Each trial delivers 3 × 5 s odor pulses (5 s on / 5 s off)
    via switch valves; overlap trials share a 15 s simultaneous-
    delivery window (10 s of concurrent odor).
    Total ~8 min including boot and shutdown.

  timing:
    base_unit: "ms"
    sample_rate: 1000            # Hz  (1 ms precision)
    preload_lead_ms: 2
    load_req_ms: 1
    rck_pulse_ms: 1
    trig_pulse_ms: 5
    setup_hold_samples: 100
    load_mode: "global"

sequence:

  # ────────────────────────────────────────────────────────────
  #  BOOT  —  start flows, camera, olfactometers to AIR
  # ────────────────────────────────────────────────────────────
  - phase: "BOOT SEQUENCE"
    duration: 11000              # 1 s warmup + 10 s stabilization
    repeat: 0
    actions:
      - device: "mfc.air_left_setpoint"
        value: *mfc_flow
        timing: 1000
      - device: "mfc.air_right_setpoint"
        value: *mfc_flow
        timing: 1000
      - device: "mfc.odor_left_setpoint"
        value: *mfc_flow
        timing: 1000
      - device: "mfc.odor_right_setpoint"
        value: *mfc_flow
        timing: 1000
      - device: "triggers.camera_continuous"
        state: true
        timing: 1000
      - device: "olfactometer.left"
        state: "AIR"
        timing: 1000
      - device: "olfactometer.right"
        state: "AIR"
        timing: 1005
      - device: "switch_valve.left"
        state: "CLEAN"
        timing: 1010
      - device: "switch_valve.right"
        state: "CLEAN"
        timing: 1015

  # ────────────────────────────────────────────────────────────
  #  OLFACTOMETER SATURATION  —  60 s to fill odor tube
  #  Switch valves stay CLEAN; odor never reaches animal yet.
  #  Microscope pulse at 60 s marks "ready to start trials".
  # ────────────────────────────────────────────────────────────
  - phase: "OLFACTOMETER SATURATION"
    duration: 65000              # 60 s saturation + 5 s buffer
    repeat: 0
    actions:
      - device: "olfactometer.left"
        state: *odor             # <-- resolves to _active_odor above
        timing: 0
      - device: "olfactometer.right"
        state: *odor
        timing: 5
      - device: "switch_valve.left"
        state: "CLEAN"
        timing: 0
      - device: "switch_valve.right"
        state: "CLEAN"
        timing: 0
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

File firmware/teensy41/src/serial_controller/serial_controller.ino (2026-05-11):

/*
  ============================================================================
  TPIC6B595 Serial-Staged Controller  v2  (Teensy 4.1)
  ----------------------------------------------------------------------------
  What changed from v1
  --------------------
  ARCHITECTURE
    - Zero heap: no String class anywhere. All parsing uses strtok on a static
      char buffer. No malloc, no fragmentation, no latency spikes.
    - Precomputed frame cache: staged bits → 6-byte frame is rebuilt only when
      the bits actually change (dirty flag). SPI path is always a memcpy + raw
      transfer with no arithmetic.
    - Non-suppressive concurrency: TEST and SEQ no longer block other commands.
      Any new command immediately cancels the running walker/sequence, applies,
      and transmits. Fast overwrite is the default.

  NEW FEATURES
    PULSE <names...> <ms>
        Turn named bits ON for <ms>, then auto-restore the pre-pulse frame.
        Up to MAX_PULSE_SLOTS independent overlapping pulses. New pulses on
        the same bits cancel the older slot and restart cleanly.

    SEQ (sequence engine)
        Pre-bake named frame sequences; trigger by name; loop or one-shot.
        Steps accumulate state (CLR resets cursor). Pre-baked at definition
        time so runtime is just a frame copy + SPI transfer.
          SEQ NEW  <name>
          SEQ ADD  <cmd> [args...] <dur_ms>   (sub-commands: CLR CTRL OD1-5
                                               CLN ODR ON OFF FRAME)
          SEQ END
          SEQ RUN  <name> [count]             (count -1 = loop forever)
          SEQ STOP
          SEQ LIST
          SEQ DEL  <name>

    PRESET (named frame snapshots)
          PRESET SAVE <name>
          PRESET LOAD <name>
          PRESET LIST
          PRESET DEL  <name>

    FRAME <h0> <h1> <h2> <h3> <h4> <h5>
        Set all six bytes directly as hex and SEND immediately.

    STATUS
        Full verbose dump: staged bits, active pulse slots, running
        sequence, test walker state, preset list, SPI speed.

    WATCH ON|OFF
        Print a "WATCH: <bitstring>" line whenever the hardware frame
        actually changes (works for staged sends, pulses, seqs, TEST).

    TEST improvements
        TEST ONCE           — single pass then stop
        TEST RANGE <a> <b> [on_ms [off_ms]]
                            — walk only valid-bit indices a..b
        TEST STEP           — manual advance by one bit (while paused)

    SPD <hz>
        Change SPI clock at runtime (e.g. SPD 4000000).

    CMD tagging
        Prefix any command with @<N> (a positive integer tag):
          @42 OD1 OLF1
        All reply lines for that command are prefixed "@42 ".
        Host software can pipeline commands and correlate replies.

    BINARY PROTOCOL (compact machine interface)
        If the first byte of a line is 0xAA the rest is a binary packet:
          [0xAA][cmd:1][len:1][payload:len][crc8:1]
        CRC-8 covers cmd+payload (NOT the len byte).
        Commands:
          0x01  SEND_FRAME   payload=6 bytes raw; sends immediately
          0x02  PULSE_FRAME  payload=6 bytes + uint32_t ms (LE)
          0x03  QUERY        payload=none; replies [0xAB][0x03][6 bytes frame]
          0x04  SEQ_RUN      payload=name (null-term or len-terminated)
          0x05  SEQ_STOP     payload=none
          0x06  PRESET_LOAD  payload=name
          0x07  PRESET_SAVE  payload=name
        Reply: [0xAB][status:1] where 0=OK, non-zero=error, except QUERY.

  COMMAND SUMMARY  (all ASCII, case-insensitive)
  -----------------------------------------------
  Base (staging):
    ON   <name> [name...]      Stage bits high
    OFF  <name> [name...]      Stage bits low
    TOGGLE <name> [name...]    Stage bits flipped
    SEND                       Push staged frame to SPI
    PRINT / STATE              Print staged bitstring
    CLEAR                      Zero staging (no send)
    RESET                      CLEAR + SEND
    FRAME <h0>..<h5>           Set raw hex frame + SEND

  Macros (auto-SEND; cancel SEQ/TEST):
    CTRL  <OLF1|OLF2|ALL>
    OD1..OD5 <OLF1|OLF2|ALL>
    CLN   <SV1|SV2|ALL> [ms]
    ODR   <SV1|SV2|ALL> [ms]

  Pulse (auto-restore, non-blocking):
    PULSE <name> [name...] <ms>
    PULSE?                     List active pulse slots

  Sequences (pre-baked, non-blocking):
    SEQ NEW  <name>
    SEQ ADD  CLR <ms>
    SEQ ADD  CTRL|OD1-5 <target> <ms>
    SEQ ADD  CLN|ODR <target> <ms>
    SEQ ADD  ON|OFF <names...> <ms>
    SEQ ADD  FRAME <h0>..<h5> <ms>
    SEQ END
    SEQ RUN  <name> [count]     count: n (n passes), -1 (loop)
    SEQ STOP
    SEQ LIST
    SEQ DEL  <name>

  Presets:
    PRESET SAVE <name>
    PRESET LOAD <name>
    PRESET LIST
    PRESET DEL  <name>

  Test walker:
    TEST START [on_ms [off_ms]]
    TEST ONCE  [on_ms [off_ms]]
    TEST RANGE <a> <b> [on_ms [off_ms]]
    TEST STEP
    TEST STOP

  Config:
    HB ON|OFF|<ms>             Heartbeat (default OFF)
    WATCH ON|OFF               Print on frame change
    SPD <hz>                   SPI clock speed
    STATUS                     Full verbose dump
    HELP

  Bit names:
    OLF1_0..OLF1_11   OLF2_0..OLF2_11   SV1_0..SV1_1   SV2_0..SV2_1

  Hardware:
    SPI MOSI=11, SCK=13, CS=10.
    Chain (nearest→farthest): OLF1_LO OLF1_HI OLF2_LO OLF2_HI SV2 SV1
    RCK latch driven externally by DAQ.
  ============================================================================
*/

#include <Arduino.h>
#include <SPI.h>
#include <string.h>
#include <stdlib.h>

// ============================================================
// ========================= CONFIG ===========================
// ============================================================
#define MAX_SEQ          8
#define MAX_SEQ_STEPS   32
#define MAX_SEQ_NAME    16
#define MAX_PRESETS      8
#define MAX_PRESET_NAME 16
#define MAX_PULSE_SLOTS 16
#define MAX_CMD_BUF    256
#define MAX_TOKENS      28
#define MAX_BIN_PAYLOAD 64
#define SPI_HZ_DEFAULT  1000000UL

// ============================================================
// ==================== FRAME ENCODING ========================
// ============================================================
// stagedFrame[] index:
//  0 = OLF1_LO  (OLF1 bits 0-7)
//  1 = OLF1_HI  (OLF1 bits 8-11, lower nibble)
//  2 = OLF2_LO  (OLF2 bits 0-7)
//  3 = OLF2_HI  (OLF2 bits 8-11, lower nibble)
//  4 = SV2      (bits 0-1)
//  5 = SV1      (bits 0-1)
// SPI wire order: index 5 first (farthest IC), index 0 last.
//
// Absolute bit space used by TEST/PULSE name→bit helpers:
//  0-11  = OLF1_0..11  (maps to f[0] bits0-7 and f[1] bits0-3)
//  16-27 = OLF2_0..11  (maps to f[2] bits0-7 and f[3] bits0-3)
//  32-33 = SV2_0..1    (f[4] bits 0-1)
//  40-41 = SV1_0..1    (f[5] bits 0-1)
constexpr int PIN_CS = 10;
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

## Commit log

2025-08-21 Add initial project structure and dependencies for Multibios
    - Created `run_protocol.py` and `viz_protocol.py` files.
    - Initialized `poetry.lock` with dependencies.
    - Added `pyproject.toml` with project metadata and dependencies including mkinit and lazy-loader.
    [hardware.yaml]
2025-08-21 Update Python version requirement and add new dependencies
    - Changed the Python version requirement to >=3.11,<3.13.
    - Added new dependencies: numpy, pyyaml, nidaqmx, and matplotlib with specified version ranges.
    -added the run protocol and viz protocol
    [hardware.yaml]
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2025-08-21 Update documentation and code references to replace NI USB-6363 with NI USB-6353
    [run_protocol.py]
2025-08-28 Add GLOBAL_LOAD_REQ support and enhance device grouping in visualization
    - Implemented GLOBAL_LOAD_REQ signal handling in run_protocol.py and viz_protocol.py, allowing for better signal management and visualization.
    - Updated color coding for GLOBAL_LOAD_REQ to improve clarity in interactive figures.
    - Enhanced device grouping logic to include a new "Global" category for better organization in plots.
    - Adjusted setup_hold_samples default value in main function to 5 for improved timing consistency.
    - Introduced new Teensy 4.1 firmware (v1_global_load.ino) to manage GLOBAL_LOAD_REQ with independent RCK latches and a 48-bit data chain.
    - Established a clear wiring summary and logical model for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
    [hardware.yaml]
2025-09-16 Refactor visualization and protocol handling
    - Moved figure creation logic from `viz_protocol.py` to a new helper module `viz_helpers.py` for better code organization and reusability.
    - Introduced `load_run_artifacts` function to streamline loading of run data and metadata.
    - Updated `make_protocol_figure` to handle digital outputs (DO), analog outputs (AO), and optional analog inputs (AI) and digital inputs (DI) with improved color grouping and layout.
    - Added a new configuration file `short_protocol.yaml` for defining odor presentation protocols with detailed timing and action sequences.
    - Cleaned up the main function in `viz_protocol.py` to utilize the new helper functions and improve rea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
    [run_protocol.py, short_protocol.yaml, viz_helpers.py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]
2025-09-16 feat(tests): Add comprehensive hardware testing utilities and examples
    - Implemented `hardware_test.py` for generating synchronized square waves on digital and analog outputs, including input monitoring and logging.
    - Created `simple_test.py` for continuous square wave generation on specified lines.
    - Added detailed README documentation for the hardware test script, outlining usage, command line options, and troubleshooting steps.
    - Introduced example scripts (`quick_test_examples.ps1` and `quick_test_examples.sh`) for quick hardware testing scenarios.
    - Updated `viz_helpers.py` to correct hovertemplate formatting for visualization.
    [hardware_test.py, run_protocol.py, viz_helpers.py]
2025-09-25 Add MultiBiOS Teensy 4.1 firmware with SD card logging
    - Implemented global command loading and latching for dual olfactometer and switch system.
    - Added non-blocking SD card logging for command loads and latch events.
    - Defined pin configurations for SPI communication, control signals, and status outputs.
    - Created a circular buffer for log messages to manage SD card writes efficiently.
    - Enhanced interrupt service routines (ISRs) for handling global load requests and RCK signals.
    - Included initialization routines for SD card and SPI setup, ensuring robust error handling.
    [hardware.yaml]
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2025-10-02 Termination Resistors/GND Vias
    Added termination resistors to avoid reflections on signal lines. Added vias to GND plane stubs to avoid antennae effects.
    [SerialOlfactometerController.kicad_pcb, SerialOlfactometerController.kicad_sch]
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2026-02-27 Add Teensy 4.1 firmware for TPIC6B595 controller and walking test
    - Implemented a serial-staged controller for TPIC6B595 with commands for ON/OFF/TOGGLE, SEND, PRINT, CLEAR, RESET, and macros for olfactometers and switches.
    - Added a walking test script to sequentially activate allowed bits with specified timing.
    - Introduced a continuous latcher tester script to send latch signals for hardware responsiveness testing.
    - Created initial test structure with __init__.py for test organization.
    [continuous_latcher.py, serial_switcher.ino, spiteensytest.ino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]
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2026-03-21 Add comprehensive documentation for running experiments and timing synchronization analysis
    - Created `running_experiments.md` to guide users through the setup, execution, and verification of olfactometer experiments with MultiBiOS.
    - Introduced a detailed hardware checklist, software setup instructions, and step-by-step protocols for running experiments.
    - Added a section on common problems and quick reference commands for ease of use.
    - Established `timing_synchronization_analysis.md` to outline strategies for achieving precise timing synchronization across various components in the experimental setup.
    - Discussed current architecture, main timing problems, and provided recommendations for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
    [experiment.py, odor_lateralization_3pulse.yaml]
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2026-04-30 Add new PowerShell scripts for rig Python integration and testing
    - Created tools/tools_rig_python.ps1 for managing Python execution within a Conda environment.
    - Added tools/run_fictrac_config_gui.ps1 to launch the FicTrac configuration GUI with optional camera trigger training.
    - Implemented tools/run_fictrac_probe.ps1 for running a live probe with FicTrac, including camera trigger setup.
    - Introduced tools/run_mfc_test.ps1 for executing MFC analog tests with configurable parameters.
    - Developed tools/run_valve_test.ps1 for running valve protocol tests with various options for output and interaction.
    [frame_index.csv, hardware.yaml]
2026-04-30 Add TeensyController for serial communication and FicTrac subprocess probe script
    - Implemented TeensyController class for thread-safe serial interface to Teensy v2 firmware, enabling odor valve control with command tagging and timeout management.
    - Added methods for setting olfactometer states, switch valves, and retrieving status.
    - Introduced fictrac_subprocess_probe.py to test various launch modes for the FicTrac subprocess, including direct execution and through command line interfaces.
    - Integrated UDP socket communication for process readiness verification.
    [hardware.yaml]
2026-04-30 Refactor TeensyController to use SerialLineMonitor for serial communication
    - Replaced direct serial communication in TeensyController with SerialLineMonitor.
    - Implemented response handling using queues for asynchronous command responses.
    - Updated methods to handle tagged commands and responses more efficiently.
    - Added unit tests for TeensyController to ensure correct response handling and timeout behavior.
    - Introduced SerialLineMonitor to manage line-oriented serial communication and transcript capture.
    - Added control plan compilation functionality to expand states and windows in experimental protocols.
    - Enhanced PowerShell scripts for better error handling and user feedback during ca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
    [frame_index.csv, hardware.yaml]
2026-04-30 Add Teensy controller and FicTrac configuration utilities
    - Implemented `teensy_controller.py` for a thread-safe serial interface to the Teensy v2 firmware, enabling high-level odor valve control with command tagging and response handling.
    - Introduced `fictrac_config.py` to manage FicTrac configuration file paths, providing functions to resolve default and custom configuration paths based on hardware settings.
    [config_camera.txt, hardware.yaml]
2026-04-30 Add new protocols for odor lateralization, FicTrac probe, independent valve testing, and odor presentation
    - Created `odor_lateralization_3pulse.yaml` for a 3-pulse odor lateralization protocol testing bilateral and unilateral conditions.
    - Introduced `run_protocol_fictrac_probe.yaml` for hardware-timed FicTrac and dual-camera startup validation.
    - Added `serial_valve_round_independent.yaml` for independent valve testing while walking through odors.
    - Implemented `short_protocol.yaml` for a basic odor presentation protocol with precise timing.
    - Developed `switch_valve_test.yaml` for testing switch valve functionality with odor presentation.
    [config_camera.txt, hardware.yaml]
2026-05-01 fixed parity between cameras a 7ms frame interval.
    [config_camera.txt, hardware.yaml, hardware_tmp_no_second_camera.yaml]
2026-05-01 Update target frame rates in hardware configuration and documentation for improved parity
    [hardware.yaml]
2026-05-02 Add tests for new functionalities and implement plot generation for interframe intervals
    - Enhance `test_experiment_fictrac_callback.py` with additional tests for:
    - Configuring headless mode in FicTrac runtime.
    - Counting rising edges and computing timeouts for camera operations.
    - Validating frame drain behavior and handling terminal exits.
    - Post-processing triggered camera recordings with chunked streams and codec retries.
    - Finalizing raw chunk retention policies based on parity checks.
    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
    [hardware.yaml]
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2026-05-02 Refactor camera timing configuration to use hardware settings and remove deprecated keys from protocol YAML files
    [config_camera.txt, hardware.yaml]
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2026-05-05 Add comprehensive tests for experiment metadata, metadata form, and run dataset
    - Introduced tests for experiment metadata functions including history management, pre and post experiment updates, and metadata file writing.
    - Added tests for the metadata form to ensure proper layout and pre-filling of values based on recent history.
    - Implemented tests for run dataset functionalities, validating directory structures, payload building, and camera recording mirroring.
    [config_camera.txt]
2026-05-11 Add dual mode controller firmware and run paths configuration
    - Implemented dual_mode_controller.ino for Teensy 4.1, enabling open-loop and serial modes with SPI communication.
    - Introduced run_paths.py to resolve output paths based on hardware configuration.
    - Created tests for run_paths to ensure correct resolution of output directories and integration with parity and FicTrac audits.
    - Added hardware.yaml configuration file for device settings, including digital and analog inputs/outputs, and data output paths.
    [config_camera.txt, hardware.yaml]
2026-06-02 Refactor odor lateralization protocol flow rate and update test configurations
    - Increased the MFC odor flow rate from 0.03 to 0.3 in the odor lateralization protocol YAML.
    - Enhanced the test for experiment FicTrac callback to include additional camera configuration fields and validation for hardware owned fields.
    - Added tests to validate imaging dataset requirements for completed microscopy runs and ensure proper handling of imaging acquisition details.
    - Introduced numeric expression evaluation for protocol timing expressions to allow dynamic calculations within the protocol.
    - Created a new script for sending two microscope trigger pulses with configurable parameters.
    - Updated hardware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
    [hardware.yaml]
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

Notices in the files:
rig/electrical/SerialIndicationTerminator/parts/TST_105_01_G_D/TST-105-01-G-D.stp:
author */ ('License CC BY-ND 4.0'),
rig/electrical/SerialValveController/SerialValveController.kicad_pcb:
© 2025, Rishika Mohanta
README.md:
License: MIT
